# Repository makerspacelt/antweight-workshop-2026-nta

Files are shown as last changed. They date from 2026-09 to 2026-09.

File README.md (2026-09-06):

## Antweight robot workshop for NTA 2026 camp

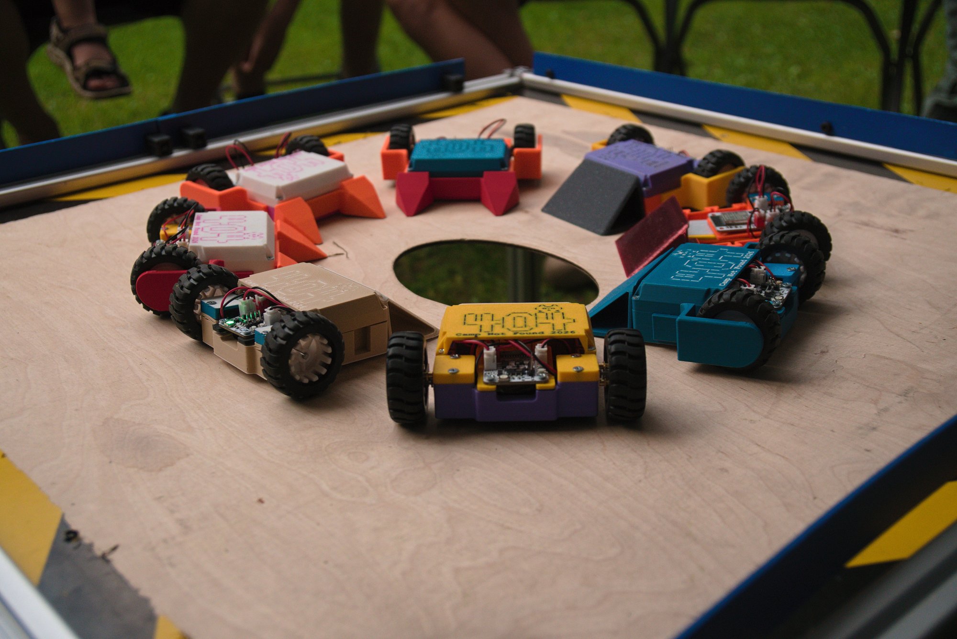
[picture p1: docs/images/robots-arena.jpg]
Robots in the arena


3D printed antweight combat robot built at the Camp Not Found 2026 workshop.
Custom ESP32 mainboard, two N20 drive motors, room for a simple brushed weapon.
Driven from a gamepad, a [custom ESP32-C3 remote](software/remote), or a
[phone over Bluetooth](software/web-app-control). Robot firmware is in
[`software/robot`](software/robot).

## Mainboard

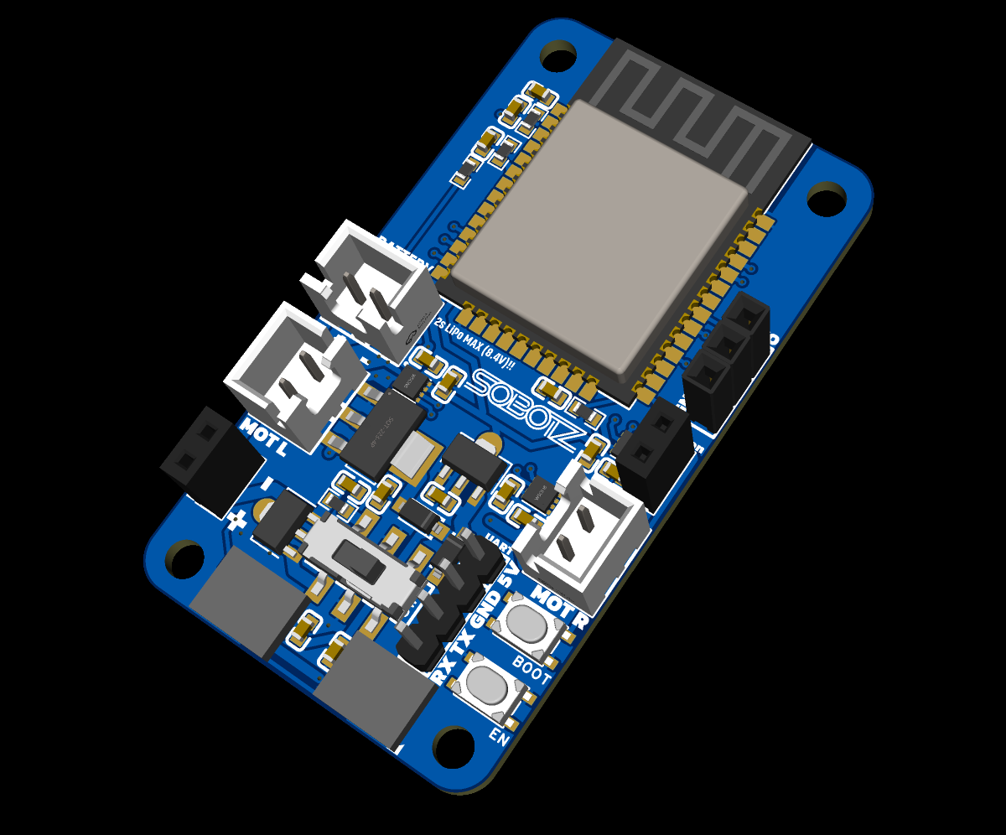
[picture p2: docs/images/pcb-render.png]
Mainboard


ESP32-WROOM-32E, runs straight off a 2S LiPo (8.4 V max).

- 3 brushed motor drivers - left, right, and a third one free so you can hang a simple
  brushed weapon off the robot. 1.8 A peak per channel.
- one servo output
- battery voltage monitoring
- up to 4 addressable RGB LEDs
- slide switch driving a mosfet to cut the main power

You need an assembled board to build the robot. If you're assembling your own, the gerbers are
in `hardware/pcb` along with the full EasyEDA project, which is also up at
https://oshwlab.com/gagaga1001/project_vcsypjyg

**Known issue:** servo power is wired to the LDO rail, which doesn't have enough current for
most servos. Fix that before you plug a servo in.

## Parts you need

| Part | Qty | Where |
|---|---|---|
| Assembled mainboard | 1 | gerbers + project in `hardware/pcb` |
| N20 motor, 6 V 600 rpm | 2 | [aliexpress](https://www.aliexpress.com/item/33022320164.html) |
| N20 wheels | 2 | [aliexpress](https://www.aliexpress.com/item/33026783171.html) |
| 2S LiPo battery, 1000-2000 mAh | 1 | preferably one with a balance plug |
| 2S LiPo charger | 1 | [aliexpress](https://www.aliexpress.com/item/1005004724167181.html) |
| 2-pin JST-XH leads | 3 | [aliexpress](https://www.aliexpress.com/item/1005004429625835.html) |
| Wood screws, ~3 mm | 12 | machine screws work too, wood screws just go into the print easier |
| Printed parts | 1 set | see below |

### Printed parts

All in `hardware/3d-printed-parts/`. `full-plate.3mf` has a whole robot laid out on one plate.

| File | Qty | |
|---|---|---|
| `base.3mf` | 1 | chassis |
| `side-wall-left.3mf` | 1 | |
| `side-wall-right.3mf` | 1 | |
| `motor-mount.3mf` | 2 | |
| `pcb-mount.3mf` | 1 | |
| `top-nta.3mf` / `top-plain.3mf` | 1 | pick one |
| `front-pusher.3mf` / `front-pyramids.3mf` | 1 | pick one |
| `remote-holder.3mf` | 1 | only if you build the custom remote |

## Assembly

Step by step: [docs/assembly-instructions.pdf](docs/assembly-instructions.pdf)

Short version: solder leads to the motors, screw the motor mounts down, push the wheels on
(D-shaped shaft, they only go on one way), slot in the side walls and the front you picked,
drop in the battery, screw the board onto its mount.

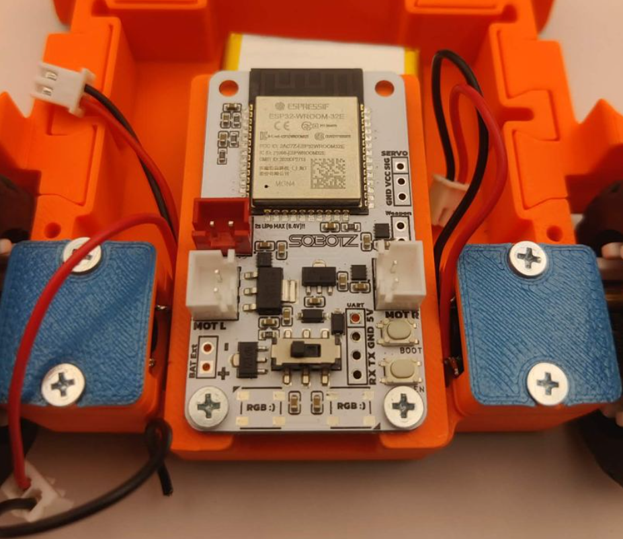
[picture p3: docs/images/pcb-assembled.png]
Assembled board


Motors go into the white JST connectors, the battery into the red one - **not the other way
round.**

Then flash `software/robot` and pair a controller.

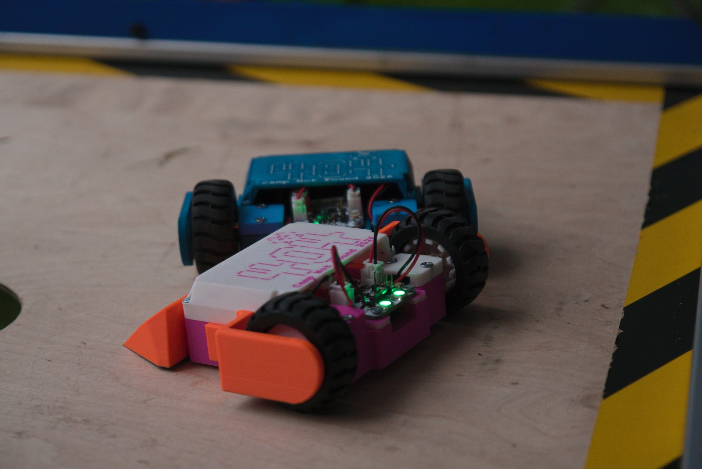
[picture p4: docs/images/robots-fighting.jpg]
Fighting


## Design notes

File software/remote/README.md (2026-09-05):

## ESP32-C3 antweight robot remote. Connection via Bluetooth

Build and upload using Arduino IDE.

Or use arduino-cli:

```sh
# Install esp32 board files
make deps
# Build firmware from remote.ino
make build
# Upload firmware
make upload PORT=/dev/ttyACM0
```

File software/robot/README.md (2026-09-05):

# Anty — Bluepad32 + Web BLE spike

One firmware, classic ESP32:

| Input | How |
|---|---|
| Web app / phone | BLE GATT write (same UUIDs as `robot2024`) |
| C3 joystick remote | same GATT client |
| DualSense / DS4 / Switch / … | Bluepad32 (BTstack HID host) |

Protocol:

```
ML<left> MR<right> MW<weapon> SL<servoL> SR<servoR>
```

- Service `99b96fd7-dd0e-49cd-b255-f7b692c3de5e`
- Char    `4fce1dff-9151-498f-aa72-581f3f9241f3`

## Build (PlatformIO + ESP-IDF)

```sh
make deps                   # once: arduino-esp32 + ESP32Servo
make build ROBOT_NAME=Anty  # env=esp32dev
make upload serial
```

`make build ENV=esp32-c3-devkitc-02` — compiles, but **no BT Classic** (no DualSense/DS4/Switch).

Default pins: `PINS_NTA_2026`. Other boards:

```sh
pio run -e esp32dev --project-option='build_flags=-DPINS_ANTY_ESPNOW'
```

## Layout

```
main/sketch.cpp     motors + BP32 gamepad map + failsafe
main/robot_gatt.c   BTstack ATT server + advertising (Anty + service UUID)
components/bluepad32* btstack  from BP32 template
```

BP32’s own config GATT stays **disabled**; we own advertising.

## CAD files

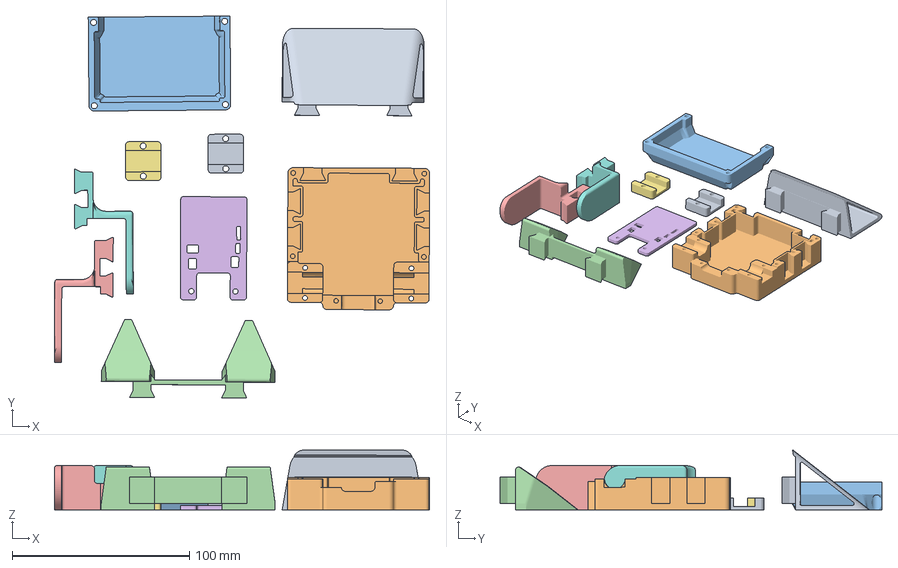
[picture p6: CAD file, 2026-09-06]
hardware/3d-printed-parts/full-plate.3mf
211.8 x 215.6 x 33.8 mm
pusher front (2)
Baze
Top
piramides
SienaLEft x 2
PCBMount
motormount x 2

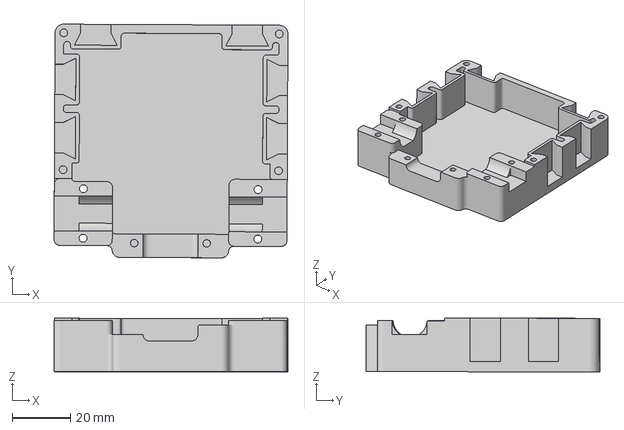
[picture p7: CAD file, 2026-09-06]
hardware/3d-printed-parts/base.3mf
80.4 x 80.3 x 18.5 mm

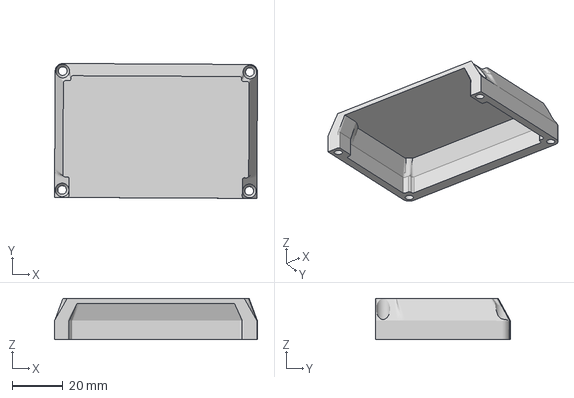
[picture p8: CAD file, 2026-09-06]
hardware/3d-printed-parts/top-plain.3mf
80.3 x 53.4 x 16.4 mm

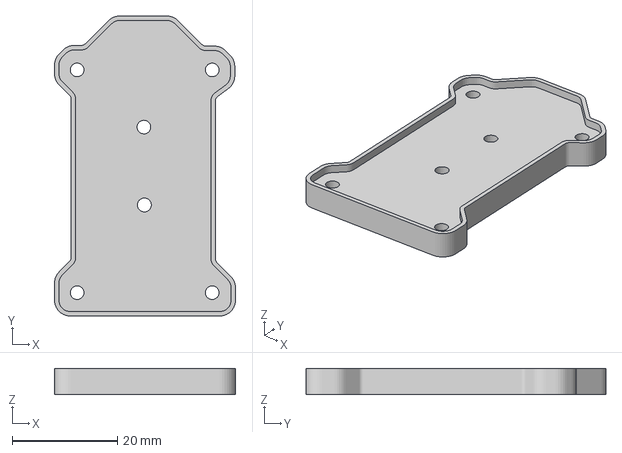
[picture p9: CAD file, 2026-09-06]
hardware/3d-printed-parts/remote-holder.3mf
34.4 x 57.0 x 5.00 mm

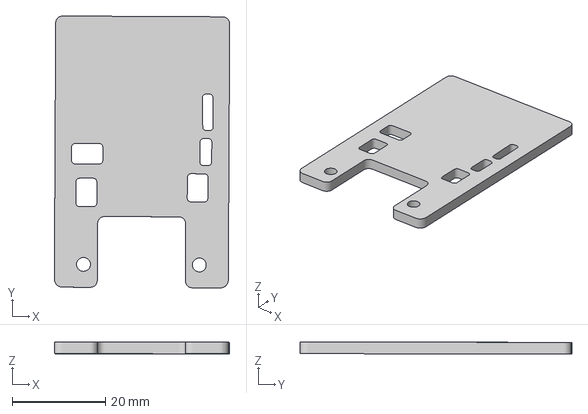
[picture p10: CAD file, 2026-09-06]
hardware/3d-printed-parts/pcb-mount.3mf
37.7 x 58.5 x 2.58 mm

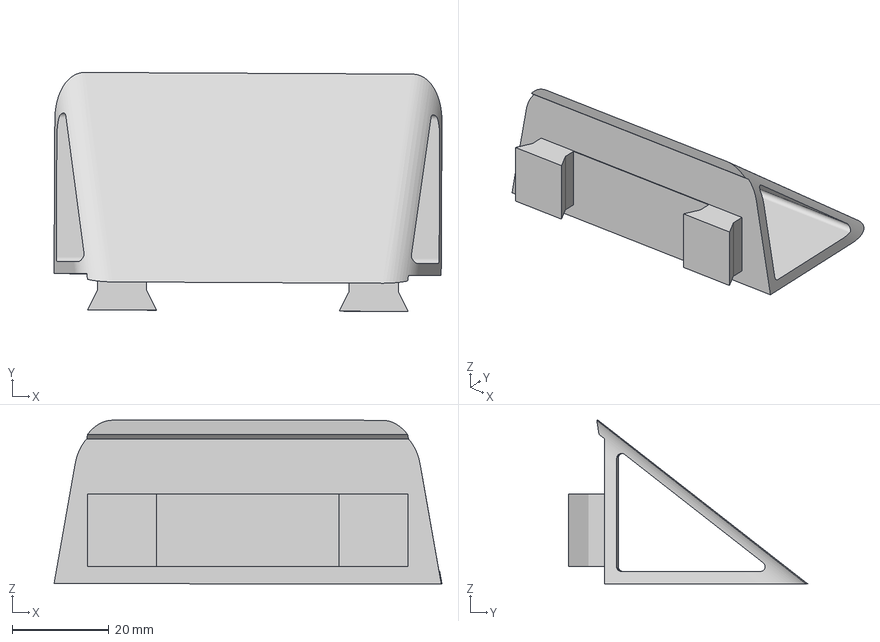
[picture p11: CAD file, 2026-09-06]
hardware/3d-printed-parts/front-pusher.3mf
80.2 x 49.4 x 33.8 mm

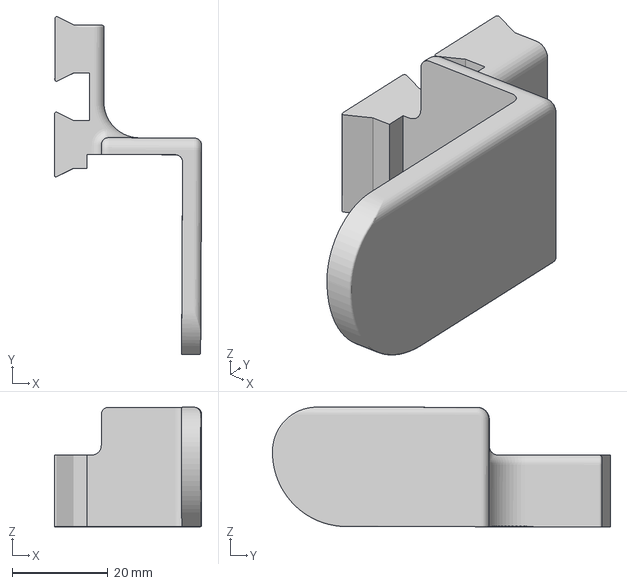
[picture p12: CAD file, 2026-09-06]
hardware/3d-printed-parts/side-wall-right.3mf
30.9 x 70.7 x 25.1 mm

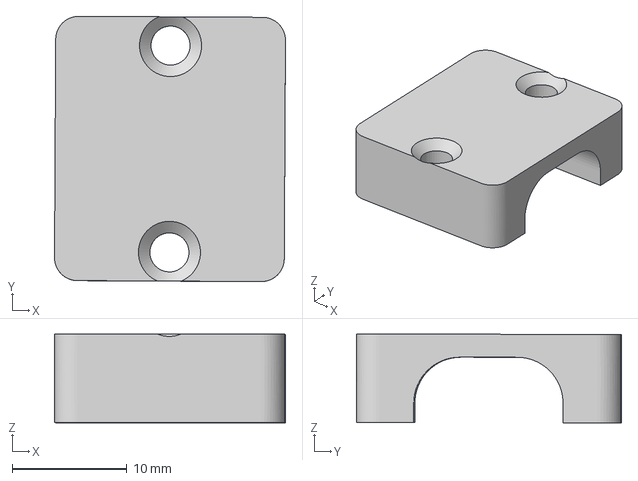
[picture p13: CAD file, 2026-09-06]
hardware/3d-printed-parts/motor-mount.3mf
20.1 x 23.1 x 7.73 mm

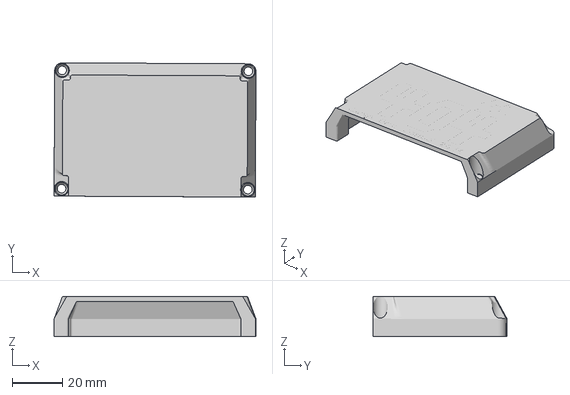
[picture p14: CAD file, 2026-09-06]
hardware/3d-printed-parts/top-nta.3mf
80.3 x 53.4 x 15.9 mm

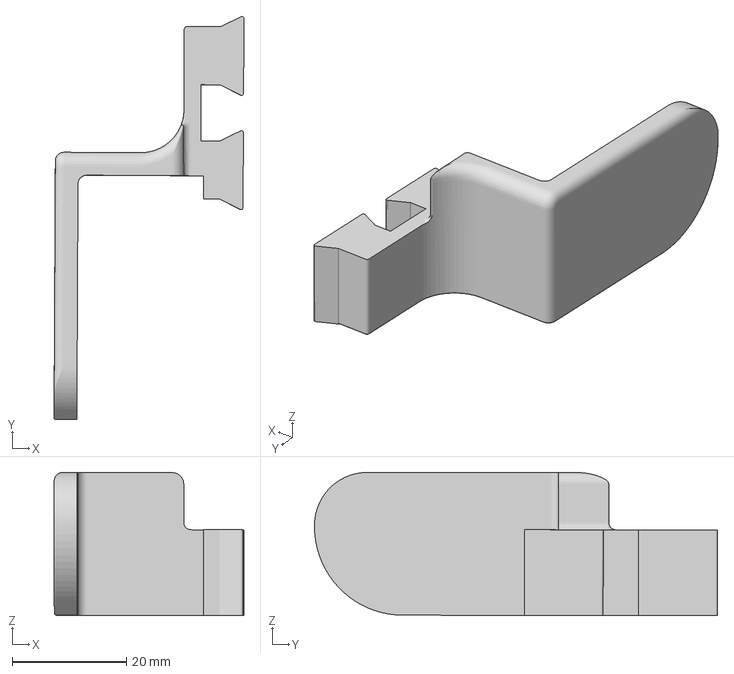
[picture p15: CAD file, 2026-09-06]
hardware/3d-printed-parts/side-wall-left.3mf
33.3 x 70.6 x 25.1 mm

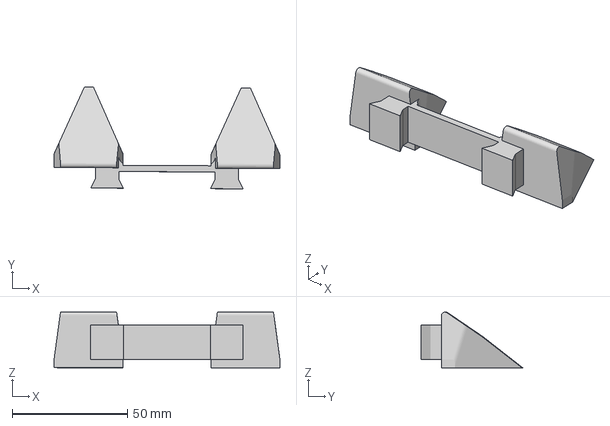
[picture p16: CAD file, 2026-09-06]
hardware/3d-printed-parts/front-pyramids.3mf
98.2 x 44.2 x 24.2 mm

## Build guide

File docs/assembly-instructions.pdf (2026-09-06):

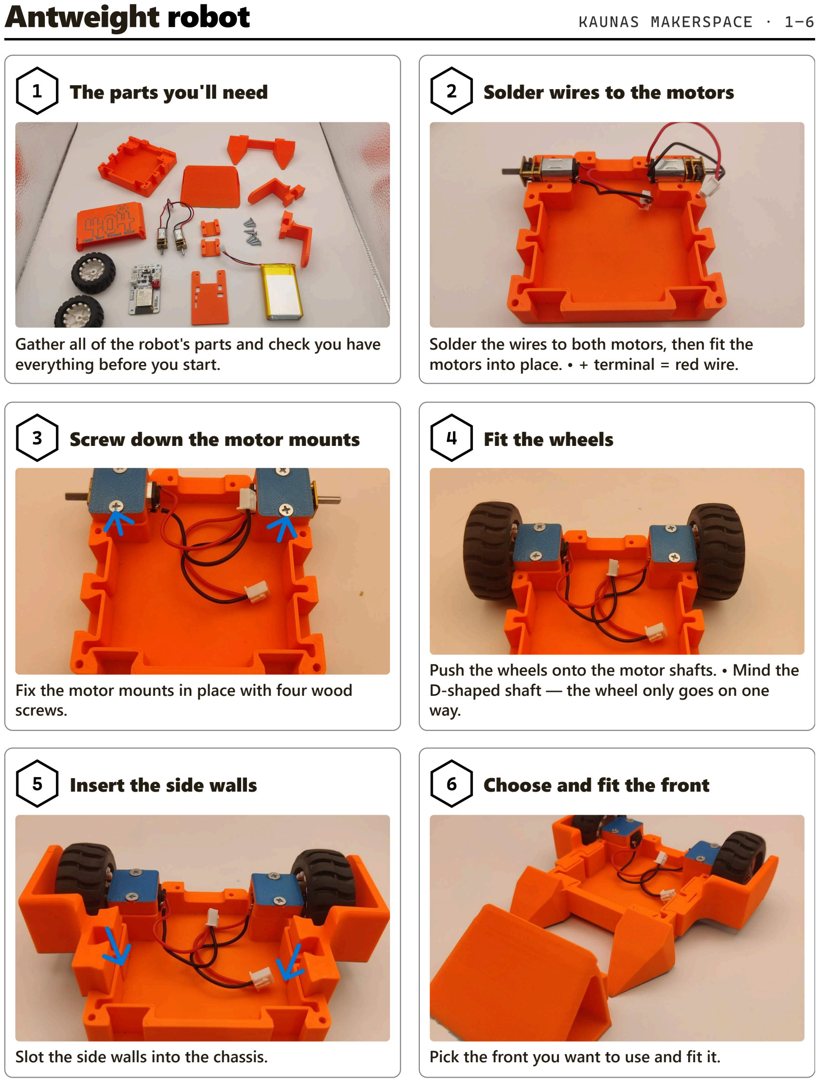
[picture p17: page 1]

Antweight robot | KAUNAS MAKERSPACE · 1–6
1 | The parts you'll need

Gather all of the robot's parts and check you have everything before you start.

### 2 Solder wires to the motors

Solder the wires to both motors, then fit the motors into place. • + terminal = red wire.

### 3 Screw down the motor mounts

Fix the motor mounts in place with four wood screws.

### 4 Fit the wheels

Push the wheels onto the motor shafts. • Mind the D-shaped shaft — the wheel only goes on one way.

### 5 Insert the side walls

Slot the side walls into the chassis.

### 6 Choose and fit the front

Pick the front you want to use and fit it.

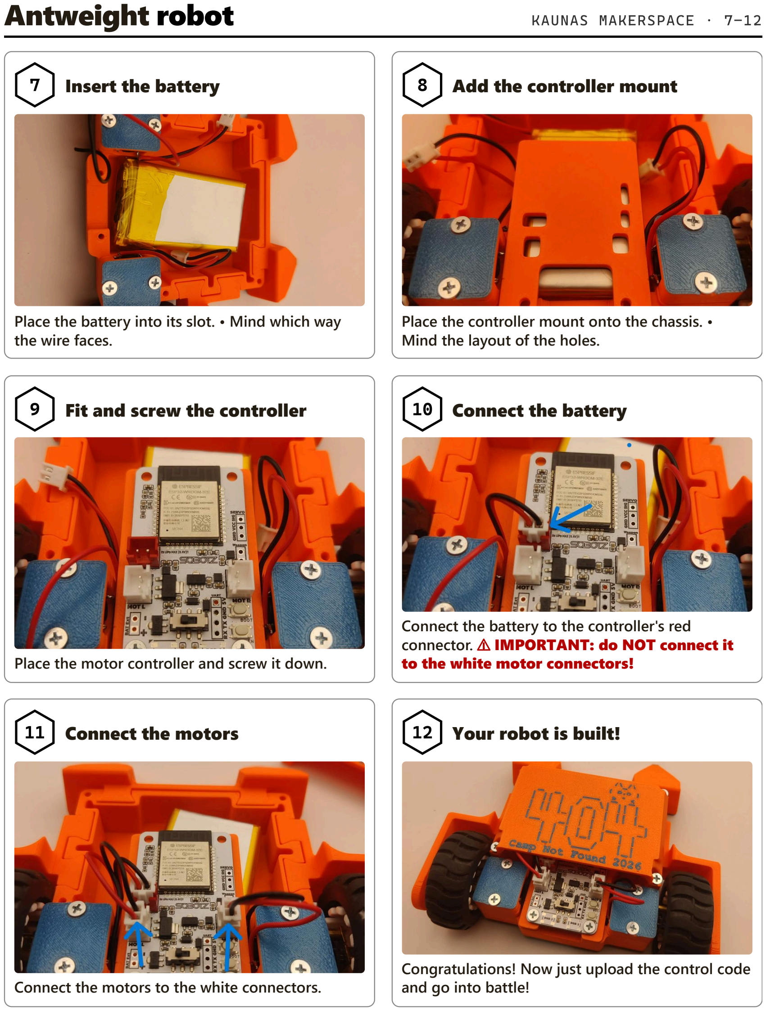
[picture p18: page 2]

Antweight robot | KAUNAS MAKERSPACE · 7–12
7 | Insert the battery

Place the battery into its slot. • Mind which way the wire faces.

### 8 Add the controller mount

Place the controller mount onto the chassis. • Mind the layout of the holes.

### 9 Fit and screw the controller

Place the motor controller and screw it down.

### 10 Connect the battery

Connect the battery to the controller's red connector. ⚠ IMPORTANT: do NOT connect it to the white motor connectors!

### 11 Connect the motors

Connect the motors to the white connectors.

### 12 Your robot is built!

Congratulations! Now just upload the control code and go into battle!

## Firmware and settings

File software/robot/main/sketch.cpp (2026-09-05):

// Bluepad32 gamepad host + Web-BLE / C3-remote GATT on one firmware.

#include "sdkconfig.h"

#include <Arduino.h>
#include <Bluepad32.h>
#include <ESP32Servo.h>
#include <Adafruit_NeoPixel.h>
#include <esp_console.h>

#include "robot_gatt.h"

// ---------------- pins -------------------------------------------------------
// #define PINS_NTA_2025 1
// #define PINS_KMS_2024 1
// #define PINS_KMS_2023 1
// #define PINS_NTA_2023 1
// Default: PINS_NTA_2026 (new board — weapon motor + single servo + LEDs)

#if defined(PINS_NTA_2025)
  #define PIN_MOT_R_IN1 13
  #define PIN_MOT_R_IN2 27
  #define PIN_MOT_L_IN1 26
  #define PIN_MOT_L_IN2 25
  #define PIN_SERVO_1 32
  #define PIN_SERVO_2 23
#elif defined(PINS_KMS_2024)
  #define PIN_MOT_R_IN1 27
  #define PIN_MOT_R_IN2 13
  #define PIN_MOT_L_IN1 26
  #define PIN_MOT_L_IN2 25
  #define PIN_SERVO_1 32
  #define PIN_SERVO_2 23
#elif defined(PINS_KMS_2023)
  #define PIN_MOT_R_IN1 26
  #define PIN_MOT_R_IN2 25
  #define PIN_MOT_L_IN1 13
  #define PIN_MOT_L_IN2 27
  #define PIN_SERVO_1 32
#elif defined(PINS_NTA_2023)
  #define PIN_MOT_R_IN1 19
  #define PIN_MOT_R_IN2 18
  #define PIN_MOT_L_IN1 17
  #define PIN_MOT_L_IN2 16
#else
  // PINS_NTA_2026 (default)
  #define PIN_MOT_R_IN1 26
  #define PIN_MOT_R_IN2 27
  #define PIN_MOT_L_IN1 16
  #define PIN_MOT_L_IN2 4
  #define PIN_MOT_W_IN1 17
  #define PIN_MOT_W_IN2 18
  #define PIN_SERVO_1 19
  #define PIN_VBAT 34
  #define PIN_LEDS 14
  #define NUM_LEDS 4
#endif

#ifndef ROBOT_NAME
#define ROBOT_NAME "Anty"
#endif

#define MOTOR_PWM_FREQ 20000
#define MOTOR_PWM_BIT_RES 8
#define CMD_TIMEOUT_MS 500
#define WEAPON_SLEW 12
#define LED_BRIGHTNESS 60
#define LED_UPDATE_MS 20

// Divider on NTA_2026: 100k+38k → scale pack voltage from ADC pin.
#ifdef PIN_VBAT
#define VBAT_DIVIDER (138.0f / 38.0f)
// Calibrated vs meter: firmware 8.06 V, meter 7.810 V → 7.810/8.06
#define VBAT_CAL 0.969f
#define VBAT_ABSENT_V 4.00f
#define VBAT_LOW_V 7.00f
#define VBAT_RECOVER_V 7.20f
#define VBAT_PRINT_MS 5000
#endif

// #define INVERT_LEFT 1
#define INVERT_RIGHT 1
// #define INVERT_WEAPON 1

// Exclusive control: first source to send a command owns the bot until failsafe.
enum ControlSrc : uint8_t { SRC_NONE = 0, SRC_GATT = 1, SRC_PAD = 2 };

static ControllerPtr myControllers[BP32_MAX_GAMEPADS];

static int cmd_left, cmd_right, cmd_weapon, cmd_servo1, cmd_servo2;
static uint32_t last_cmd_ms;
static int weapon_out;
static int servo1_last = -1, servo2_last = -1;
static ControlSrc active_src = SRC_NONE;

#ifdef PIN_SERVO_1
static Servo servo1;
#endif
#ifdef PIN_SERVO_2
static Servo servo2;
#endif

#ifdef PIN_LEDS
static Adafruit_NeoPixel leds(NUM_LEDS, PIN_LEDS, NEO_GRB + NEO_KHZ800);
#endif

#ifdef PIN_VBAT
static float vbat = 0.0f;
static bool battery_low = false;

static float read_vbat() {
  uint32_t mv = 0;
  for (int i = 0; i < 8; i++) mv += analogReadMilliVolts(PIN_VBAT);
  float v = (mv / 8.0f) / 1000.0f * VBAT_DIVIDER * VBAT_CAL;
  if (vbat <= 0.0f) vbat = v;
  else vbat = vbat * 0.8f + v * 0.2f;

  if (vbat < VBAT_ABSENT_V) battery_low = false;
  else if (vbat < VBAT_LOW_V) battery_low = true;
  else if (vbat > VBAT_RECOVER_V) battery_low = false;
  return vbat;
}

static int cmd_vbat(int argc, char** argv) {
  (void)argc;
  (void)argv;
  float v = read_vbat();
  if (v < VBAT_ABSENT_V) {
    Console.printf("vbat=%.2f V (absent / USB only?) low=%d\n", v, (int)battery_low);
  } else {
    Console.printf("vbat=%.2f V low=%d\n", v, (int)battery_low);
  }
  return 0;
}

static void register_vbat_cmd() {
  const esp_console_cmd_t cmd = {
      .command = "vbat",
      .help = "Read pack voltage (PIN_VBAT)",
      .hint = NULL,
      .func = &cmd_vbat,
      .argtable = NULL,
  };
  esp_console_cmd_register(&cmd);
}
#endif

static bool any_pad_connected() {
  for (auto c : myControllers) {
    if (c && c->isConnected()) return true;
  }
  return false;
}

static bool any_controller_present() {
  return robot_gatt_client_connected() || any_pad_connected();
}

// ---- motors -----------------------------------------------------------------
static void driveMotor(int pinA, int pinB, int spd) {
  spd = constrain(spd, -255, 255);
  if (spd >= 0) {
    ledcWrite(pinA, 255);
    ledcWrite(pinB, 255 - spd);
  } else {
    ledcWrite(pinB, 255);
    ledcWrite(pinA, 255 + spd);
  }
}

static void setLeft(int s) {
#ifdef INVERT_LEFT
  s = -s;
#endif
  driveMotor(PIN_MOT_L_IN1, PIN_MOT_L_IN2, s);
}
static void setRight(int s) {
#ifdef INVERT_RIGHT
  s = -s;
#endif
  driveMotor(PIN_MOT_R_IN1, PIN_MOT_R_IN2, s);
}
#ifdef PIN_MOT_W_IN1
static void setWeapon(int s) {
#ifdef INVERT_WEAPON
  s = -s;
#endif
  driveMotor(PIN_MOT_W_IN1, PIN_MOT_W_IN2, s);
}
#endif

// Returns false if another source owns control.
static bool try_apply_command(ControlSrc src, int l, int r, int w, int s1, int s2, uint32_t t) {
  if (active_src != SRC_NONE && active_src != src) return false;
  active_src = src;
  cmd_left = constrain(l, -255, 255);
  cmd_right = constrain(r, -255, 255);
  cmd_weapon = constrain(w, -255, 255);
  cmd_servo1 = constrain(s1, 0, 180);
  cmd_servo2 = constrain(s2, 0, 180);
  last_cmd_ms = t;
  return true;
}

// ---- LEDs -------------------------------------------------------------------
#ifdef PIN_LEDS
static void update_leds(uint32_t now, bool failsafe, int drive_l, int drive_r, int drive_w) {
  uint32_t color;
  const bool driving =
      !failsafe && (abs(drive_l) > 15 || abs(drive_r) > 15 || abs(drive_w) > 15);

#ifdef PIN_VBAT
  // Low pack: red blink, but only while motors are idle (2S + 2A draw sag).
  if (battery_low && !driving) {
    color = (now % 400 < 200) ? leds.Color(255, 30, 0) : leds.Color(50, 0, 0);
    for (int i = 0; i < NUM_LEDS; i++) leds.setPixelColor(i, color);
    leds.show();
    return;
  }
#endif

  if (!failsafe) {
    // Recent command from the active source
    color = leds.Color(0, 255, 0);
  } else if (any_controller_present()) {
    // Linked but idle — slow green breathe (still "have a remote", no packets)
    uint32_t p = now % 2400;
    uint8_t g = (p < 1200) ? (uint8_t)(p * 180 / 1200) : (uint8_t)((2400 - p) * 180 / 1200);
    if (g < 15) g = 15;
    color = leds.Color(0, g, 0);
  } else {
    // Nobody connected — blue breathe (waiting to pair/connect)
    uint32_t p = now % 1600;
    uint8_t b = (p < 800) ? (uint8_t)(p * 255 / 800) : (uint8_t)((1600 - p) * 255 / 800);
    if (b < 20) b = 20;
    color = leds.Color(0, 0, b);
  }

  for (int i = 0; i < NUM_LEDS; i++) leds.setPixelColor(i, color);
  leds.show();
}
#endif

// ---- Bluepad32 --------------------------------------------------------------
static void onConnectedController(ControllerPtr ctl) {
  for (int i = 0; i < BP32_MAX_GAMEPADS; i++) {
    if (myControllers[i] == nullptr) {
      Console.printf("Pad connected slot=%d model=%s\n", i, ctl->getModelName());
      myControllers[i] = ctl;
      return;
    }
  }
  Console.println("Pad connected but no slot");
}

static void onDisconnectedController(ControllerPtr ctl) {
  for (int i = 0; i < BP32_MAX_GAMEPADS; i++) {
    if (myControllers[i] == ctl) {
      Console.printf("Pad disconnected slot=%d\n", i);
      myControllers[i] = nullptr;
      if (active_src == SRC_PAD) active_src = SRC_NONE;
      return;
    }
  }
}

// Arcade mix: full forward authority, softened steering.
// Turn: cubic expo (soft center) then * TURN_GAIN/512 (~40% at full stick).
#define TURN_GAIN 102

static void processGamepad(ControllerPtr ctl) {
  int x = ctl->axisX();
  int y = ctl->axisY();
  if (abs(x) < 30) x = 0;
  if (abs(y) < 30) y = 0;

  // axis ±512 → ±255
  int drive = constrain((int)((long)-y * 255 / 512), -255, 255);

  // Cubic expo on turn, then attenuate: t^3/512^2 keeps sign, |t|<1 soft.
  long t = constrain(x, -512, 512);
  long turn_exp = t * t * t / (512 * 512);  // ±512
  int turn = constrain((int)(turn_exp * TURN_GAIN / 512), -255, 255);

  int l = constrain(drive - turn, -255, 255);
  int r = constrain(drive + turn, -255, 255);

  int w = 0;
  if (ctl->throttle() > 50) {
    w = constrain((int)((long)ctl->throttle() * 255 / 1023), 0, 255);
  }
  if (ctl->b()) w = 255;

  int s1 = 90, s2 = 90;
  if (ctl->a()) s1 = 0;
  if (ctl->y()) s1 = 180;

  try_apply_command(SRC_PAD, l, r, w, s1, s2, millis());
}

static void processControllers() {
  for (auto c : myControllers) {
    if (c && c->isConnected() && c->hasData() && c->isGamepad()) {
      processGamepad(c);
    }
  }
}

// ---- setup / loop -----------------------------------------------------------
void setup() {
  Console.printf("Anty — BP32 + robot GATT\n");
  Console.printf("FW %s\n", BP32.firmwareVersion());

#ifdef PIN_LEDS
  leds.begin();
  leds.setBrightness(LED_BRIGHTNESS);
  leds.clear();
  leds.show();
#endif

#ifdef PIN_SERVO_1
  servo1.setPeriodHertz(50);
  servo1.attach(PIN_SERVO_1, 400, 2400);
#endif
#ifdef PIN_SERVO_2
  servo2.setPeriodHertz(50);
  servo2.attach(PIN_SERVO_2, 400, 2400);
#endif

  ledcAttach(PIN_MOT_R_IN1, MOTOR_PWM_FREQ, MOTOR_PWM_BIT_RES);
  ledcAttach(PIN_MOT_R_IN2, MOTOR_PWM_FREQ, MOTOR_PWM_BIT_RES);
  ledcAttach(PIN_MOT_L_IN1, MOTOR_PWM_FREQ, MOTOR_PWM_BIT_RES);
  ledcAttach(PIN_MOT_L_IN2, MOTOR_PWM_FREQ, MOTOR_PWM_BIT_RES);
#ifdef PIN_MOT_W_IN1
  ledcAttach(PIN_MOT_W_IN1, MOTOR_PWM_FREQ, MOTOR_PWM_BIT_RES);
  ledcAttach(PIN_MOT_W_IN2, MOTOR_PWM_FREQ, MOTOR_PWM_BIT_RES);
  setWeapon(0);
#endif
  setLeft(0);
  setRight(0);

#ifdef PIN_VBAT
  analogSetPinAttenuation(PIN_VBAT, ADC_11db);
  pinMode(PIN_VBAT, INPUT);
#endif

  BP32.setup(&onConnectedController, &onDisconnectedController, true);
  BP32.enableBLEService(false);
  BP32.enableVirtualDevice(false);

#ifdef PIN_VBAT
  register_vbat_cmd();
  read_vbat();
#endif

  robot_gatt_start(ROBOT_NAME);

  const uint8_t* addr = BP32.localBdAddress();
  Console.printf("BD %02X:%02X:%02X:%02X:%02X:%02X name=%s\n", addr[0], addr[1], addr[2],
                 addr[3], addr[4], addr[5], ROBOT_NAME);
  Console.println("Ready: exclusive control (GATT | pad), LEDs on");
#ifdef PIN_VBAT
  Console.println("Shell: type 'vbat'");
#endif
}

void loop() {
  const uint32_t now = millis();

  if (BP32.update()) {
    processControllers();
  }

  // GATT path (phone / C3 remote) — ignored while a pad owns control.
  robot_cmd_t gc;
  robot_gatt_get_cmd(&gc);
  if (gc.valid) {
    try_apply_command(SRC_GATT, gc.left, gc.right, gc.weapon, gc.servo_l, gc.servo_r, gc.last_ms);
  }

  // Drop owner after silence so the other method can take over cleanly.
  if (active_src != SRC_NONE && (now - last_cmd_ms) > CMD_TIMEOUT_MS) {
    active_src = SRC_NONE;
  }

  const bool failsafe = (active_src == SRC_NONE) || ((now - last_cmd_ms) > CMD_TIMEOUT_MS);
  int l = failsafe ? 0 : cmd_left;
  int r = failsafe ? 0 : cmd_right;
  int w = failsafe ? 0 : cmd_weapon;

  if (w > weapon_out) weapon_out = min(w, weapon_out + WEAPON_SLEW);
  else if (w < weapon_out) weapon_out = max(w, weapon_out - WEAPON_SLEW);

  setLeft(l);
  setRight(r);
#ifdef PIN_MOT_W_IN1
  setWeapon(weapon_out);
#else
  (void)weapon_out;
#endif

#ifdef PIN_SERVO_1
  if (!failsafe && cmd_servo1 != servo1_last) {
    servo1.write(cmd_servo1);
    servo1_last = cmd_servo1;
  }
#endif
#ifdef PIN_SERVO_2
  if (!failsafe && cmd_servo2 != servo2_last) {
    servo2.write(cmd_servo2);
    servo2_last = cmd_servo2;
  }
#endif

#ifdef PIN_VBAT
  static uint32_t last_vbat_ms = 0;
  if (now - last_vbat_ms >= 200) {
    last_vbat_ms = now;
    read_vbat();
  }
  static uint32_t last_vbat_print = 0;
  if (now - last_vbat_print >= VBAT_PRINT_MS) {
    last_vbat_print = now;
    if (vbat >= VBAT_ABSENT_V) Console.printf("vbat %.2f V%s\n", vbat, battery_low ? " LOW" : "");
  }
#endif

#ifdef PIN_LEDS
  static uint32_t last_led = 0;
  if (now - last_led >= LED_UPDATE_MS) {
    last_led = now;
    update_leds(now, failsafe, l, r, weapon_out);
  }
#endif

  delay(1);
}

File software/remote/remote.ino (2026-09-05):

/*
  Antweight BLE remote - ESP32-C3 + joystick + button
  GATT client talking to robot-bp32 / web-app protocol.

  Board: ESP32C3 Dev Module  |  Arduino-ESP32 core 3.x  |  no extra libs

  Wiring:
    Joystick X  -> GPIO4 (ADC1)  // forward / back on this module
    Joystick Y  -> GPIO3 (ADC1)  // left / right turn
    Button      -> GPIO2 to GND (weapon toggle / pairing)
    Joystick VCC-> 3V3, GND -> GND
    LED         -> LED_BUILTIN (GPIO8 on most C3 devkits, active-low)

  BUTTON:
    short press  -> toggle weapon on/off
    hold 3 s     -> PAIR: LED blinks fast, scan for robot, strongest RSSI

  Protocol (same as web app):
    "ML%d MR%d MW%d SL%d SR%d"  write-without-response
  Service 99b96fd7-dd0e-49cd-b255-f7b692c3de5e
  Char    4fce1dff-9151-498f-aa72-581f3f9241f3

  Last robot address is stored in NVS; power-up reconnects automatically.
  Note: GPIO2 is a strapping pin — pair is runtime long-press only.

  BLE connect/scan block for seconds — they run on a worker task so loop()
  keeps polling the button and printing serial info.
*/

#include <Arduino.h>
#include <BLEDevice.h>
#include <BLEUtils.h>
#include <BLEScan.h>
#include <BLEAdvertisedDevice.h>
#include <BLEClient.h>
#include <BLERemoteCharacteristic.h>
#include <Preferences.h>

#define PIN_JOY_X 4
#define PIN_JOY_Y 3
#define PIN_BTN 2
// ESP32-C3 DevKit "LED_BUILTIN" is a WS2812 on GPIO8 (via RGB_BUILTIN), not a
// plain GPIO — must use rgbLedWrite(), not digitalWrite().

#define ROBOT_SERVICE_UUID "99b96fd7-dd0e-49cd-b255-f7b692c3de5e"
#define ROBOT_CMD_UUID "4fce1dff-9151-498f-aa72-581f3f9241f3"

#define SEND_INTERVAL_MS 20  // ~50 Hz
#define INFO_INTERVAL_MS 500
#define ADC_MAX 4095
#define DEADZONE 200
#define WEAPON_SPEED 255
#define PAIR_HOLD_MS 3000
#define SCAN_SECONDS 4
#define RECONNECT_MS 4000
#define CONNECT_TIMEOUT_MS 2000
#define PAIR_BLINK_MS 50

// Prefer snappy link (1.25 ms units): 7.5–15 ms, latency 0, timeout 4 s
#define CONN_INTERVAL_MIN 6
#define CONN_INTERVAL_MAX 12
#define CONN_LATENCY 0
#define CONN_TIMEOUT 400

// Stick orientation tweaks
// #define INVERT_DRIVE 1
// #define INVERT_TURN 1
// #define ROBOT_NAME_FILTER "Anty"

#define LED_BRIGHT 40  // WS2812 full-scale is harsh on a desk

enum BleJob : uint8_t { JOB_NONE = 0, JOB_RECONNECT, JOB_PAIR };

static Preferences prefs;
static BLEClient* client = nullptr;
static BLERemoteCharacteristic* cmdChar = nullptr;
static BLEAddress* savedAddr = nullptr;
static uint8_t savedAddrType = 0;
static char savedAddrStr[18] = "-";

static int centerX = ADC_MAX / 2, centerY = ADC_MAX / 2;
static volatile bool weaponOn = false;

static bool prevBtn = HIGH;
static uint32_t pressStart = 0;
static bool holdHandled = false;

static volatile bool linkDrop = false;
static volatile bool pairingBlink = false;
static volatile BleJob bleJob = JOB_NONE;
static volatile bool bleBusy = false;
static volatile bool wantPair = false;  // sticky until worker accepts JOB_PAIR
static uint32_t lastReconnectTry = 0;

static bool isConnected();  // fwd

// USB serial monitors want CRLF; printf("...\n") alone stair-steps the cursor.
#define LOG(msg) Serial.print(F(msg "\r\n"))
#define LOGF(fmt, ...) Serial.printf(fmt "\r\n", ##__VA_ARGS__)

// ---- LED (WS2812 via Arduino RGB API) ---------------------------------------
static void ledRgb(uint8_t r, uint8_t g, uint8_t b) {
#ifdef RGB_BUILTIN
  rgbLedWrite(RGB_BUILTIN, r, g, b);
#else
  rgbLedWrite(8, r, g, b);
#endif
}

static void ledOff() { ledRgb(0, 0, 0); }

static void ledInit() { ledOff(); }

// Linked=green, reconnect busy=dim amber, else off. Pairing uses its own blink task.
static void ledShowStatus() {
  if (pairingBlink) return;
  if (isConnected()) {
    ledRgb(0, LED_BRIGHT / 2, 0);
  } else if (bleBusy) {
    ledRgb(LED_BRIGHT / 2, LED_BRIGHT / 4, 0);  // amber while connect/scan
  } else {
    ledOff();
  }
}

static void pairingBlinkTask(void* /*arg*/) {
  while (pairingBlink) {
    ledRgb(LED_BRIGHT, LED_BRIGHT, LED_BRIGHT);  // white flash
    vTaskDelay(pdMS_TO_TICKS(PAIR_BLINK_MS));
    ledOff();
    vTaskDelay(pdMS_TO_TICKS(PAIR_BLINK_MS));
  }
  vTaskDelete(nullptr);
}

static void pairingBlinkStart() {
  if (pairingBlink) return;
  pairingBlink = true;
  xTaskCreate(pairingBlinkTask, "pairled", 2048, nullptr, 1, nullptr);
}

static void pairingBlinkStop() {
  pairingBlink = false;
  vTaskDelay(pdMS_TO_TICKS(PAIR_BLINK_MS * 3));
  ledOff();
}

// ---- helpers ----------------------------------------------------------------
static int axisToSpeed(int raw, int center) {
  int d = raw - center;
  if (d > -DEADZONE && d < DEADZONE) return 0;
  if (d > 0) d -= DEADZONE;
  else d += DEADZONE;
  int span = (ADC_MAX / 2) - DEADZONE;
  if (span < 1) span = 1;
  return constrain((int)((long)d * 255 / span), -255, 255);
}

static bool isConnected() {
  return client && client->isConnected() && cmdChar;
}

static void clearLink() {
  cmdChar = nullptr;
  if (client) {
    if (client->isConnected()) client->disconnect();
  }
}

static void rememberAddr(BLEAddress addr, uint8_t type) {
  String s = addr.toString();
  prefs.putString("addr", s);
  prefs.putUChar("atype", type);
  if (savedAddr) delete savedAddr;
  savedAddr = new BLEAddress(addr);
  savedAddrType = type;
  strncpy(savedAddrStr, s.c_str(), sizeof(savedAddrStr) - 1);
  savedAddrStr[sizeof(savedAddrStr) - 1] = 0;
}

class ClientCbs : public BLEClientCallbacks {
  void onConnect(BLEClient* c) override {
    LOG("BLE connected");
    c->updateConnParams(CONN_INTERVAL_MIN, CONN_INTERVAL_MAX, CONN_LATENCY, CONN_TIMEOUT);
  }
  void onDisconnect(BLEClient* c) override {
    (void)c;
    LOG("BLE disconnected");
    cmdChar = nullptr;
    linkDrop = true;
  }
};

static ClientCbs clientCbs;

static bool attachCmdChar() {
  BLERemoteService* svc = client->getService(ROBOT_SERVICE_UUID);
  if (!svc) {
    LOG("service not found");
    return false;
  }
  cmdChar = svc->getCharacteristic(ROBOT_CMD_UUID);
  if (!cmdChar) {
    LOG("cmd char not found");
    return false;
  }
  if (!cmdChar->canWrite() && !cmdChar->canWriteNoResponse()) {
    LOG("cmd char not writable");
    cmdChar = nullptr;
    return false;
  }
  LOG("cmd char OK");
  return true;
}

static bool connectAddr(BLEAddress addr, uint8_t type) {
  clearLink();
  if (!client) {
    client = BLEDevice::createClient();
    client->setClientCallbacks(&clientCbs);
  }
  LOGF("Connecting %s type=%u ...", addr.toString().c_str(), (unsigned)type);
  if (!client->connect(addr, type, CONNECT_TIMEOUT_MS)) {
    LOG("connect failed");
    return false;
  }
  client->setMTU(185);
  if (!attachCmdChar()) {
    clearLink();
    return false;
  }
  rememberAddr(addr, type);
  LOG("Paired/connected");
  return true;
}
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

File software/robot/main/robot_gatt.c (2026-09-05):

// Custom ATT server: one writable characteristic, text protocol:
//   "ML%d MR%d MW%d SL%d SR%d"
// Coexists with Bluepad32 HID host (BP32 BLE config service must stay disabled).
//
// IMPORTANT: gap_advertisements_set_data() does NOT copy — buffers must be static.

#include "robot_gatt.h"

#include <stdio.h>
#include <string.h>

#include "btstack.h"
#include "ble/att_db.h"
#include "ble/att_db_util.h"
#include "ble/att_server.h"
#include "bluetooth_gatt.h"

#include "bt/uni_bt.h"

#include "esp_timer.h"
#include "freertos/FreeRTOS.h"
#include "freertos/semphr.h"

// LE General Discoverable | BR/EDR Not Supported (same as BP32 service adv).
// The BR/EDR-not-supported AD flag only affects LE scanners; classic pads still work.
#define ADV_FLAGS 0x06

// att_db_util_* reverse_128() internally — pass UUID **string/big-endian** order.
// Advertising packets need **little-endian** wire order (see k*UuidLe below).
// 99b96fd7-dd0e-49cd-b255-f7b692c3de5e
static const uint8_t kServiceUuidBe[16] = {
    0x99, 0xb9, 0x6f, 0xd7, 0xdd, 0x0e, 0x49, 0xcd,
    0xb2, 0x55, 0xf7, 0xb6, 0x92, 0xc3, 0xde, 0x5e,
};
// 4fce1dff-9151-498f-aa72-581f3f9241f3
static const uint8_t kCmdUuidBe[16] = {
    0x4f, 0xce, 0x1d, 0xff, 0x91, 0x51, 0x49, 0x8f,
    0xaa, 0x72, 0x58, 0x1f, 0x3f, 0x92, 0x41, 0xf3,
};
// LE wire order for AD type 0x07 complete 128-bit service list
static const uint8_t kServiceUuidLe[16] = {
    0x5e, 0xde, 0xc3, 0x92, 0xb6, 0xf7, 0x55, 0xb2,
    0xcd, 0x49, 0x0e, 0xdd, 0xd7, 0x6f, 0xb9, 0x99,
};

static uint16_t cmd_value_handle;
static char cmd_buf[48] = "ML0 MR0 MW0 SL0 SR0";
static char device_name[16] = ROBOT_NAME;

// Must outlive gap_advertisements_set_data / gap_scan_response_set_data.
static uint8_t adv_data[31];
static uint8_t adv_data_len;
static uint8_t scan_rsp[31];
static uint8_t scan_rsp_len;

static robot_cmd_t g_cmd;
static SemaphoreHandle_t g_cmd_mu;
static hci_con_handle_t g_client = HCI_CON_HANDLE_INVALID;
static hci_con_handle_t g_periph = HCI_CON_HANDLE_INVALID;  // slave link (phone/remote)
static bool g_client_is_writer;  // true only after a write to our char

static btstack_context_callback_registration_t g_start_reg;
static btstack_packet_callback_registration_t g_hci_event_cb;
static bool g_started;

// Prefer low-latency link for WebBLE joystick stream (units: 1.25 ms / 10 ms).
// 6..12 → 7.5..15 ms interval, 0 slave latency, 4 s supervision.
#define GATT_CONN_INTERVAL_MIN 6
#define GATT_CONN_INTERVAL_MAX 12
#define GATT_CONN_LATENCY 0
#define GATT_SUPERVISION_TIMEOUT 400

static uint32_t now_ms(void) {
  return (uint32_t)(esp_timer_get_time() / 1000ULL);
}

static void parse_cmd(const char* s, uint16_t len) {
  int ml = g_cmd.left, mr = g_cmd.right, mw = g_cmd.weapon;
  int sl = g_cmd.servo_l, sr = g_cmd.servo_r;

  char tmp[48];
  if (len >= sizeof(tmp)) len = sizeof(tmp) - 1;
  memcpy(tmp, s, len);
  tmp[len] = 0;

  if (sscanf(tmp, "ML%d MR%d MW%d SL%d SR%d", &ml, &mr, &mw, &sl, &sr) >= 2 ||
      sscanf(tmp, "ML%d MR%d SL%d SR%d", &ml, &mr, &sl, &sr) >= 2) {
    if (xSemaphoreTake(g_cmd_mu, pdMS_TO_TICKS(10)) == pdTRUE) {
      g_cmd.left = (int16_t)ml;
      g_cmd.right = (int16_t)mr;
      g_cmd.weapon = (int16_t)mw;
      g_cmd.servo_l = (int16_t)sl;
      g_cmd.servo_r = (int16_t)sr;
      g_cmd.last_ms = now_ms();
      g_cmd.valid = true;
      xSemaphoreGive(g_cmd_mu);
    }
  }
}

static uint16_t att_read_cb(hci_con_handle_t conn, uint16_t handle, uint16_t offset,
                            uint8_t* buffer, uint16_t buffer_size) {
  (void)conn;
  if (handle == cmd_value_handle) {
    return att_read_callback_handle_blob((const uint8_t*)cmd_buf, (uint16_t)strlen(cmd_buf),
                                         offset, buffer, buffer_size);
  }
  return 0;
}

static int att_write_cb(hci_con_handle_t conn, uint16_t handle, uint16_t transaction_mode,
                        uint16_t offset, uint8_t* buffer, uint16_t buffer_size) {
  (void)transaction_mode;
  if (handle != cmd_value_handle || offset != 0 || buffer_size == 0) {
    return ATT_ERROR_REQUEST_NOT_SUPPORTED;
  }
  // First write proves this connection is a real robot client (not a BP32 HID link).
  g_client = conn;
  g_client_is_writer = true;

  if (buffer_size >= sizeof(cmd_buf)) buffer_size = sizeof(cmd_buf) - 1;
  memcpy(cmd_buf, buffer, buffer_size);
  cmd_buf[buffer_size] = 0;
  parse_cmd(cmd_buf, buffer_size);
  return ATT_ERROR_SUCCESS;
}

static void failsafe_clear(void) {
  if (xSemaphoreTake(g_cmd_mu, pdMS_TO_TICKS(10)) == pdTRUE) {
    g_cmd.left = g_cmd.right = g_cmd.weapon = 0;
    g_cmd.valid = false;
    xSemaphoreGive(g_cmd_mu);
  }
}

static void restart_advertising(void) {
  // BTstack usually restarts connectable adv itself; be explicit after our client leaves.
  gap_advertisements_enable(1);
}

static void request_fast_conn_params(hci_con_handle_t h) {
  int rc = gap_request_connection_parameter_update(h, GATT_CONN_INTERVAL_MIN, GATT_CONN_INTERVAL_MAX,
                                                   GATT_CONN_LATENCY, GATT_SUPERVISION_TIMEOUT);
  printf("robot_gatt: request conn params %d..%d (1.25ms) latency=%d -> rc=%d\n",
         GATT_CONN_INTERVAL_MIN, GATT_CONN_INTERVAL_MAX, GATT_CONN_LATENCY, rc);
}

static void hci_packet_handler(uint8_t packet_type, uint16_t channel, uint8_t* packet, uint16_t size) {
  (void)channel;
  (void)size;
  if (packet_type != HCI_EVENT_PACKET) return;
  uint8_t event = hci_event_packet_get_type(packet);
  if (event == HCI_EVENT_LE_META) {
    switch (hci_event_le_meta_get_subevent_code(packet)) {
      case HCI_SUBEVENT_LE_CONNECTION_COMPLETE: {
        hci_con_handle_t h = hci_subevent_le_connection_complete_get_connection_handle(packet);
        uint16_t interval = hci_subevent_le_connection_complete_get_conn_interval(packet);
        uint16_t latency = hci_subevent_le_connection_complete_get_conn_latency(packet);
        printf("robot_gatt: LE conn complete handle=%u interval=%u (%.2fms) latency=%u\n",
               (unsigned)h, (unsigned)interval, interval * 1.25f, (unsigned)latency);
        break;
      }
      case HCI_SUBEVENT_LE_CONNECTION_UPDATE_COMPLETE: {
        uint8_t status = hci_subevent_le_connection_update_complete_get_status(packet);
        hci_con_handle_t h = hci_subevent_le_connection_update_complete_get_connection_handle(packet);
        uint16_t interval = hci_subevent_le_connection_update_complete_get_conn_interval(packet);
        uint16_t latency = hci_subevent_le_connection_update_complete_get_conn_latency(packet);
        printf("robot_gatt: LE conn update handle=%u status=%u interval=%u (%.2fms) latency=%u\n",
               (unsigned)h, (unsigned)status, (unsigned)interval, interval * 1.25f, (unsigned)latency);
        break;
      }
      default:
        break;
    }
  }
}
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
